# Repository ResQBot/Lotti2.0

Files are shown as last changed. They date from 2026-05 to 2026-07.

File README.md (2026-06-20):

# Lotti2.0 by Res.Q Bots Austria

Lotti2.0 is the seccond generation of our tracked **U**rban **S**earch and **E**xploration **R**obot (or USER).

We hope that any info you find in this repository helps you in your quest to develop your own USER, or robot of any other kind.
If you have any questions or want to partner up, feel free to contact us.

## Repository content:

### getting_started
contains a (more or less) detailed introduction to the whole topic of using Ubuntu and ROS, using our ROS packages and how to develop your own. This is a work in progress and you will definitely need addittional information to get deeper into ROS development.

### hardware
contains all (more or less) the hardware information and the CAD files.

### resources
contains user manuals, guidebooks, datasheets, etc. for motory, sensors, parts, ... used in our current robot.

### src 
contains our **ROS2 code** to control the robot and make use of its sensors.

&nbsp;
## Disclaimer
Please remember, that we are not professionals in the field of robotics, but merely curious students fooling around. While (most) code and designs you'll find here may work for us, they might not work for you and we do not take any responsibility for potential danger arising from the use of our ideas.

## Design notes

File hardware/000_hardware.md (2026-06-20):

# 🚀 Lotti 2.0 Hardware and CAD

This folder contains the mechanical CAD design, hardware documentation, and Bill of Materials (BOM) for **Lotti 2.0**, our RoboCup Rescue League robot developed for the **2026 RoboCup World Championship in Incheon, South Korea**.

The documentation explains the project structure, design philosophy, and the components used to build the robot.

---

# 📂 CAD Description

The main assembly, **`Lotti2_Main Assembly`**, contains the complete robot including the manipulator arm.

To simplify transportation and maintenance, the robot is divided into several modular assemblies.

## 🏗️ Center Module

Contains the main electronic components, including:

* Power distribution system
* Onboard computers
* Flipper mechanism motors

## ⚙️ Passive E-Module

Contains:

* Bearing-mounted shafts
* Structural drivetrain components
* Passive track support elements

No active drivetrain components are installed in this module.

## 🔩 Active E-Module

Contains:

* Chain drive motors
* Track drivetrain
* Transmission shafts
* Power transmission components

## 🤖 Manipulator Arm Assembly

Contains:

* Complete robotic arm
* End-effector mounting structure
* Arm electronics and sensors
* Mechanical transmission components

---

## 🎯 Design Philosophy

The modular design provides several advantages:

* Easier transportation
* Faster assembly during competitions
* Simplified maintenance
* Rapid replacement of damaged modules
* Improved accessibility to electronics and drivetrain components

---

# 📋 Bill of Materials (BOM)

## Main Robot

| Item No. | Component | Qty. | Notes | Manufacturer / Supplier |
| --- | --- | ---- | --- | --- |
| 1 | CubeMars AK10-9 V2.0 KV60 | 2 | Chain drive motors | https://www.cubemars.com/de/product/ak10-9-v2-0-kv60-robotic-actuator.html  |
| 2 | Unitree GO-M8010-6 Motor | 4 | Flipper mechanism | https://shop.unitree.com/products/go1-motor |
| 3 | Aluminum Profile 20x20 Type B Slot 6 | – | Center module frame | https://www.motedis.at/de/Aluprofil-20x20-B-Typ-Nut-6 |
| 4 | Internal Corner Bracket 21.6×21.6×15.8 | 16 | Structural frame | https://3d24.com/Winkel-Innenwinkel-21-6x21-6x15-8-Stahlguss-verzinkt/12560 |
| 5 | M4 T-Slot Nut Type B Slot 6 | 70 | Frame assembly | https://3d24.com/Nutenstein-M4-Nut-6-Typ-B-mit-Steg-Stahl-verzinkt/10697 |
| 6 | MINIX Z300-0dB | 1 | Main compute unit | https://www.minix.com.hk/products/minix-z300-0db-fanless-mini-pc-eu |
| 7 | Greenworks G24B4 Battery | 6 | Used with custom battery management system | https://greenworkstools.eu/products/24v-battery-4ah |
| 8 | Timing Belt | 4 | – | – |
| 9 | Waterjet-Cut Parts | – | Custom manufactured | – |
| 10 | Tower Profile | – | -- | – |
| 11 | Emergency Stop Switch | 1 | Safety system | https://www.conrad.at |
| 12 | Cameras | – | Vision system | – |
| 13 | Livox MID-360 | 1 | LiDAR sensor | https://www.livoxtech.com/de/mid-360 |
| 14 | HDMI Bulkhead Connector | 1 | External access port | Amazon |
| 15 | USB Extension | 1 | External access port | – |
| 16 | LAN Extension | 1 | External access port | – |
| 17 | PoolCare Track Belt | 4 | Flipper chain | https://www.hellopool.de/de/p/11620 |
| 18 | Waveshare USB-to-CAN Adapter | 1 | CAN communication | Amazon |
| 19 | XT60 Connector | 2 | Power interface | https://www.reichelt.at |
| 20 | M12 Sensor Cable (4-pin) | 1 | Sensor connection | https://www.reichelt.at |
| 21 | Amphenol M12A-04PFFP-SF8001 Socket | 1 | External interface | https://www.mouser.at |

---

## 🦾 Manipulator Arm

| Item No. | Component | Qty. | Notes | Manufacturer / Supplier |
| --- | --- | --- | --- | --- |
| 1 | Sweep Dynamics Cricket Drive MK II | 6 | Gearboxes | https://www.sweepdynamics.com/products/8247658741794 |
| 2 | NEMA 17 (23 mm) | 2 | Joint actuators | https://www.omc-stepperonline.com |
| 3 | NEMA 17 Stepper Motor | 4 | Joint actuators | – |
| 4 | MakerBase Servo42D | 6 | Closed-loop stepper driver | https://makerbase3d.com |
| 5 | RS485 Dongle | 1 | Communication interface | – |
| 6 | Aluminum Profile | 500 mm | Arm structure | – |
| 7 | Aluminum Profile | 500 mm | Arm structure | – |
| 8 | Camera | 1 | Visual feedback | – |
| 9 | Thermal Camera | 1 | Victim detection | – |
| 10 | Magnetic Sensor | 1 | Position sensing | – |
| 11 | ESP Controller | 1 | Arm control electronics | – |
| 12 | M12 Cable | 1 | Power and communication | – |
| 13 | M12 Socket | 1 | External connection | – |
| 14 | XT60 Connector | 1 | Power connection | – |
| 15 | USB Socket | 1 | Data connection | – |

---

# 🖨️ Manufacturing

Several additional custom parts are used throughout the robot.

### FDM Printed Components

Most non-load-critical components are manufactured using FDM printing with:

* Nobufil ABSx
* Nobufil PCTG
* PLA

### SLS Printed Components

The remaining actuator and precision mechanical components are manufactured using **Selective Laser Sintering (SLS)** for improved strength and dimensional accuracy.

---

# 🏆 RoboCup 2026

This robot was developed for participation in the **RoboCup Rescue League World Championship 2026** in **Incheon, South Korea**.

nm

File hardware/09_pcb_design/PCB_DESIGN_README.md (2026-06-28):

# PCB Desing section
This is the PCB Design section of the storage and Documentation area

# Power Delivery
The Power delivery is split into two section, one section gets the two battery inputs, merges them to a stable 24V for further use and also secures two individual 24V lines for driving the Motors. A lot of measurements also happen here.

The other part is the Conversion to regulate the 24V for the Motors to 12V for some sensores, the STM32 and also the Control PC and optional 5V for other things.

## Open Problems witht the PCB (ideas and stuff for v3)
- Rework PD Traces
- include relay for smooth change for the PC 12V line.

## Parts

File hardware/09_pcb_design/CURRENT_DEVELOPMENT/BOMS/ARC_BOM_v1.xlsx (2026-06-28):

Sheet: ARC_SecBoard_v1
Reference | Qty | Value | MOUSER NR. | Gegenstück | DNP | Exclude from BOM | Exclude from Board | Footprint | Link | Datasheet
BAT1_INPUT1,BAT2_INPUT1,J6,J7,J8,J9,J10,J11 | 8 | VP026584000AG | 523-VP026584000AG |  |  |  |  | Bickel_STD_LIB:SHDR4W100P1016_2X2_2032X1830X2850P | https://www.mouser.at/ProductDetail/Amphenol-Anytek/VP026584000AG?qs=T3oQrply3y8ZXElTBVt2Rg%3D%3D | http://www.anytek.com.tw/UserUpFiles/20181025/d41_CP3hmn_a.pdf
C1,C2,C3,C4,C11,C12 | 6 | 1uF | 80-C0805X105J5RAUTO |  |  |  |  | Capacitor_SMD:C_0805_2012Metric_Pad1.18x1.45mm_HandSolder | https://www.mouser.at/ProductDetail/KEMET/C0805X105J5RACAUTO?qs=3Rah4i%252BhyCEIBfdnjuP76g%3D%3D | ~
C5,C8 | 2 | 4.7nF | 80-C0805C472F2GECAUT |  |  |  |  | Capacitor_SMD:C_0805_2012Metric_Pad1.18x1.45mm_HandSolder | https://www.mouser.at/ProductDetail/KEMET/C0805C472F2GECAUTO?qs=MLItCLRbWsxYq%252BaGNtguHw%3D%3D | ~
C6,C7,C9,C10,C14,C42 | 6 | 47nF | C0805C473F8TACTU (https://www.mouser.at/ProductDetail/KEMET/C0805C473F8TACTU?qs=Znm5pLBrcAKsHNAcWSl52g%3D%3D) |  |  |  |  | Capacitor_SMD:C_0805_2012Metric_Pad1.18x1.45mm_HandSolder | https://www.mouser.at/ProductDetail/KEMET/C0805C473F8TACTU?qs=Znm5pLBrcAKsHNAcWSl52g%3D%3D | ~
C15,C17,C18,C20 | 4 | 100nF | 80-C0805R104J5RACTU |  |  |  |  | Capacitor_SMD:C_0805_2012Metric_Pad1.18x1.45mm_HandSolder | https://www.mouser.at/ProductDetail/KEMET/C0805R104J5RACTU?qs=RcG8xmE7yp2JeihV4l474Q%3D%3D | ~
C16,C19 | 2 | 0.1uF | 80-C0805R104J5RACTU |  |  |  |  | Capacitor_SMD:C_0805_2012Metric_Pad1.18x1.45mm_HandSolder | https://www.mouser.at/ProductDetail/KEMET/C0805R104J5RACTU?qs=RcG8xmE7yp2JeihV4l474Q%3D%3D | ~
CurMeas_BATT1,CurMeas_BATT2 | 2 | HLSR_16-P | 61-HLSR16-P |  |  |  |  | Bickel_STD_LIB:HLSR16P | https://www.mouser.at/ProductDetail/LEM/HLSR-16-P?qs=Vi0JKjFBtYk%252B%2FFkGD82vGg%3D%3D
D1,D3 | 2 | 1N4007 | 637-1N4007 |  |  |  |  | Diode_THT:D_DO-41_SOD81_P10.16mm_Horizontal | https://www.mouser.at/ProductDetail/Diotec-Semiconductor/1N4007?qs=OlC7AqGiEDmK9mU1uTiCkg%3D%3D | http://www.vishay.com/docs/88503/1n4001.pdf
D2,D6 | 2 | BZX84Cxx | 637-BZX84C2V4 |  |  |  |  | Package_TO_SOT_SMD:SOT-23 | https://www.mouser.at/ProductDetail/Diotec-Semiconductor/BZX84C2V4?qs=OlC7AqGiEDkxkJbs7iMTqw%3D%3D | https://diotec.com/tl_files/diotec/files/pdf/datasheets/bzx84c2v4.pdf
D4,D5 | 2 | SMBJ26A-E3_52 | 625-SMBJ26A-E3 |  |  |  |  | Bickel_STD_LIB:DIOM5436X244N | https://www.mouser.at/ProductDetail/Vishay-General-Semiconductor/SMBJ26A-E3-52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 | http://www.vishay.com/docs/88392/smbj.pdf
FUSEHOLDER1,FUSEHOLDER2 | 2 | 30A | 576-178.6764.0001 |  |  |  |  | Bickel_STD_LIB:17867640001 | https://www.mouser.at/ProductDetail/Littelfuse/178.6764.0001?qs=gu7KAQ731UTQ5alyjBY5mw%3D%3D | http://www.littelfuse.com/~/media/commercial-vehicle/datasheets/automotive-fuse-holders/mini/littelfuse-fuseholder-mini-fl1-pcb-mount.pdf
IC1,IC4 | 2 | FDS6690A | 512-FDS6690A |  |  |  |  | Bickel_STD_LIB:SOIC127P600X175-8N | https://www.mouser.at/ProductDetail/onsemi/FDS6690A?qs=HK%252BeIG1iaajCQ7GvPyNvug%3D%3D | https://www.onsemi.com/pub/Collateral/FDS6690A-D.PDF
IC7 | 1 | PI4ULS5V202UEX | 729-PI4ULS5V202UEX |  |  |  |  | Bickel_STD_LIB:SOP65P490X110-8N | https://www.mouser.at/ProductDetail/Diodes-Incorporated/PI4ULS5V202UEX?qs=iC14BvcgY%2F0LieFnOYBbzw%3D%3D | https://www.diodes.com//assets/Datasheets/PI4ULS5V202.pdf
J1 | 1 | EmerStop_Con1 | 737-25SH-B-02-TR | 737-25CH-B-02 + 737-25CTB-R |  |  |  | Bickel_STD_LIB:25SHB02TR | https://www.mouser.at/ProductDetail/Adam-Tech/25SH-B-02-TR?qs=HoCaDK9Nz5ewYeC9%2FRQ9dg%3D%3D | https://app.adam-tech.com/products/download/data_sheet/196905/25sh-b-xx-tr-data-sheet.pdf
J2 | 1 | EmerStop_Con2 | 737-25SH-B-02-TR | 737-25CH-B-02 + 737-25CTB-R |  |  |  | Bickel_STD_LIB:25SHB02TR | https://www.mouser.at/ProductDetail/Adam-Tech/25SH-B-02-TR?qs=HoCaDK9Nz5ewYeC9%2FRQ9dg%3D%3D | https://app.adam-tech.com/products/download/data_sheet/196905/25sh-b-xx-tr-data-sheet.pdf
J3 | 1 | 640455-5 | 571-6404555 | 571-1375820-5 + 571-13758193 |  |  |  | Bickel_STD_LIB:HDRRA5W88P0X254_1X5_1270X775X610P | https://www.mouser.at/ProductDetail/TE-Connectivity/640455-5?qs=X1mjqRbeMc5kyjdl11VSpA%3D%3D | https://www.te.com/commerce/DocumentDelivery/DDEController?Action=srchrtrv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
J4,J5 | 2 | 1792863 | 651-1792863 |  |  |  |  | Bickel_STD_LIB:1792863 | https://www.mouser.at/ProductDetail/Phoenix-Contact/1792863?qs=YjJcVSlHJPU69DDcZ8WVCg%3D%3D | https://www.phoenixcontact.com/online/portal/pi/pxc/product_detail_page/!ut/p/z1/5VddT_IwFP4rvBfcWdp9j0ucREDRGUDZbpa260h1X24V1F9vCzNEo_PCePFmy0nWduec9nl6DuGBI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
J12 | 1 | 25SH-B-02-TR | 737-25SH-B-02-TR | 737-25CH-B-02 + 737-25CTB-R |  |  |  | Bickel_STD_LIB:25SHB02TR | https://www.mouser.at/ProductDetail/JST-Commercial/B4B-XH-ALFSN?qs=cdbOS8ANM9CfC08d%252BywhFw%3D%3D | https://app.adam-tech.com/products/download/data_sheet/196905/25sh-b-xx-tr-data-sheet.pdf
J22 | 1 | B4B-XH-A_LF__SN_ | 306-B4BXHALFSN |  |  |  |  | Bickel_STD_LIB:B4BXHALFSN | https://www.mouser.at/ProductDetail/JST-Commercial/B4B-XH-ALFSN?qs=cdbOS8ANM9CfC08d%252BywhFw%3D%3D | https://datasheet.lcsc.com/szlcsc/JST-Sales-America-B4B-XH-A-LF-SN_C144395.pdf
J28,J37 | 2 | 25SHB02TR | 306-B4BXHALFSN |  |  |  |  | Bickel_STD_LIB:25SHB02TR | https://www.mouser.at/ProductDetail/JST-Commercial/B4B-XH-ALFSN?qs=cdbOS8ANM9CfC08d%252BywhFw%3D%3D | https://app.adam-tech.com/products/download/data_sheet/196905/25sh-b-xx-tr-data-sheet.pdf
K1,K2 | 2 | T9AS1D12-24 | 655-T9AS1D12-24 |  |  |  |  | Bickel_STD_LIB:T9AS1D1224 | 655-T9AS1D12-24 | https://www.te.com/commerce/DocumentDelivery/DDEController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
Q1,Q6 | 2 | BSS138 | 512-BSS138 |  |  |  |  | Package_TO_SOT_SMD:SOT-23 | https://www.mouser.at/ProductDetail/onsemi/BSS138?qs=HK%252BeIG1iaahCeqBvjB4arg%3D%3D | https://www.onsemi.com/pub/Collateral/BSS138-D.PDF
Q2,Q3 | 2 | IPD70P04P4L08ATMA2 | 726-IPD70P04P4L08ATM |  |  |  |  | Bickel_STD_LIB:IPD70P04P4L08ATMA2 | https://www.mouser.at/ProductDetail/Infineon-Technologies/IPD70P04P4L08ATMA2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 | https://www.infineon.com/dgdl/Infineon-IPD70P04P4L-08-DataSheet-v01_02-EN.pdf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
R1,R3,R5,R7 | 4 | 6k8 | 756-WCR1206-6K8FI |  |  |  |  | Resistor_SMD:R_1206_3216Metric_Pad1.30x1.75mm_HandSolder | https://www.mouser.at/ProductDetail/Welwyn-Components-TT-Electronics/WCR1206-6K8FI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 | ~
R2,R4,R6,R8 | 4 | 1k | 756-WCR1206-1K0FI |  |  |  |  | Resistor_SMD:R_1206_3216Metric_Pad1.30x1.75mm_HandSolder | https://www.mouser.at/ProductDetail/Welwyn-Components-TT-Electronics/WCR1206-1K0FI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 | ~
R9,R11,R14,R18 | 4 | 5k1 | 756-WCR1206-5K1FI |  |  |  |  | Resistor_SMD:R_1206_3216Metric_Pad1.30x1.75mm_HandSolder | https://www.mouser.at/ProductDetail/Welwyn-Components-TT-Electronics/WCR1206-5K1FI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 | ~
R10,R12,R31,R33,R32 | 4 | 10k | 756-WCR1206-10KFI |  |  |  |  | Resistor_SMD:R_1206_3216Metric_Pad1.30x1.75mm_HandSolder | https://www.mouser.at/ProductDetail/Welwyn-Components-TT-Electronics/WCR1206-10KFI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 | ~
R13,R17 | 2 | 100kOhm | 756-WCR1206-100KFI |  |  |  |  | Resistor_SMD:R_1206_3216Metric_Pad1.30x1.75mm_HandSolder | https://www.mouser.at/ProductDetail/Welwyn-Components-TT-Electronics/WCR1206-100KFI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 | ~
U2,U7 | 2 | LM74700 | 595-LM74700QDBVRQ1 |  |  |  |  | Package_TO_SOT_SMD:SOT-23-6 | https://www.mouser.at/ProductDetail/Texas-Instruments/LM74700QDBVRQ1?qs=j%252B1pi9TdxUYjAZhGV8eSkQ%3D%3D | http://www.ti.com/lit/gpn/LM74700-Q1
U4 | 1 | NUCLEO-L432KC | 511-NUCLEO-L432KC | 872-920-0171-01 |  |  |  | NUCLEO:MODULE_NUCLEO-L432KC | https://www.mouser.at/ProductDetail/STMicroelectronics/NUCLEO-L432KC?qs=qzCNEk%252BRr%252BajjPvxjwWK5g%3D%3D

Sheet: ARC_ConBoard_v1
Reference | Qty | Value | MOUSER NR. | Gegenstück | Link | DNP | Exclude from BOM | Exclude from Board | Footprint | Link2 | Datasheet
C21,C28 | 2 | C5750X7S2A156M250KB | 810-C5750X7S2A156M |  | https://www.mouser.at/ProductDetail/TDK/C5750X7S2A156M250KB?qs=NRhsANhppD%2F9BqQqutmwLg%3D%3D |  |  |  | Bickel_STD_LIB:C5750_Commercial |  | https://product.tdk.com/system/files/dam/doc/product/capacitor/ceramic/mlcc/catalog/mlcc_commercial_midvoltage_en.pdf
C22,C29,C38,C40,C39 | 5 | 100nF | 80-C0805R104J5RACTU |  | https://www.mouser.at/ProductDetail/KEMET/C0805R104J5RACTU?qs=RcG8xmE7yp2JeihV4l474Q%3D%3D |  |  |  | Capacitor_SMD:C_0805_2012Metric_Pad1.18x1.45mm_HandSolder |  | ~
C23,C30 | 2 | 15nF | 80-C0805C153K5HAUTO |  | https://www.mouser.at/ProductDetail/KEMET/C0805C153K5HACAUTO?qs=2FIyTMJ0hNmdPhqlC7uDGg%3D%3D |  |  |  | Capacitor_SMD:C_0805_2012Metric_Pad1.18x1.45mm_HandSolder |  | ~
C24,C31 | 2 | 2.2uF | 80-C0805X225K3RAUTO |  | https://www.mouser.at/ProductDetail/KEMET/C0805X225K3RACAUTO?qs=HBWAp0VN4RiOFLf7ztePRQ%3D%3D |  |  |  | Capacitor_SMD:C_0805_2012Metric_Pad1.18x1.45mm_HandSolder |  | ~
C25,C32 | 2 | 470nF | 80-C1206C474M1REAULR |  | https://www.mouser.at/ProductDetail/KEMET/C1206C474M1RECAUTO7210?qs=55YtniHzbhDbiphzg7KKzQ%3D%3D |  |  |  | Capacitor_SMD:C_1206_3216Metric_Pad1.33x1.80mm_HandSolder |  | ~
C26,C33,C34,C262 | 4 | 100pF | 80-C0805C101F1G |  | https://www.mouser.at/ProductDetail/KEMET/C0805C101F1GACTU?qs=PvkUd2vn8WpeBlgrApNklg%3D%3D |  |  |  | Capacitor_SMD:C_0805_2012Metric_Pad1.18x1.45mm_HandSolder |  | ~
C27,C35 | 2 | EEH-ZC1E560P | 667-EEH-ZC1E560P |  | https://www.mouser.at/ProductDetail/Panasonic/EEH-ZC1E560P?qs=7UCyOFMWVHYdN59awcl%252BRg%3D%3D |  |  |  | Bickel_STD_LIB:EEHZA1E101XP |  | http://industrial.panasonic.com/cdbs/www-data/pdf/RDD0000/ABA0000C1234.pdf
C36 | 1 | 10uF | 80-C0805X106J8RAUTO |  | https://www.mouser.at/ProductDetail/KEMET/C0805X106J8RACAUTO?qs=HXFqYaX1Q2wKi4kcOiFe3g%3D%3D |  |  |  | Capacitor_SMD:C_0805_2012Metric_Pad1.18x1.45mm_HandSolder |  | ~
C37 | 1 | 22uF | 80-C0805C226K9PACTU |  | https://www.mouser.at/ProductDetail/KEMET/C0805C226K9PACTU?qs=CmJlwSR1kv6i2XEByn7wWw%3D%3D |  |  |  | Capacitor_SMD:C_0805_2012Metric_Pad1.18x1.45mm_HandSolder |  | ~
D7 | 1 | 1N4007 | 637-1N4007 |  | https://www.mouser.at/ProductDetail/Diotec-Semiconductor/1N4007?qs=OlC7AqGiEDmK9mU1uTiCkg%3D%3D |  |  |  | Diode_THT:D_DO-41_SOD81_P10.16mm_Horizontal |  | http://www.vishay.com/docs/88503/1n4001.pdf
IC2 | 1 | FDS6690A | 512-FDS6690A |  | https://www.mouser.at/ProductDetail/onsemi/FDS6690A?qs=HK%252BeIG1iaajCQ7GvPyNvug%3D%3D |  |  |  | Bickel_STD_LIB:SOIC127P600X175-8N |  | https://www.onsemi.com/pub/Collateral/FDS6690A-D.PDF
J3 | 1 | 640455-5 | 571-6404555 | 571-1375820-5 + 571-13758193 | https://www.mouser.at/ProductDetail/TE-Connectivity/640455-5?qs=X1mjqRbeMc5kyjdl11VSpA%3D%3D |  |  |  | Bickel_STD_LIB:HDRRA5W88P0X254_1X5_1270X775X610P |  | https://www.te.com/commerce/DocumentDelivery/DDEController?Action=srchrtrv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
J4 | 1 | 1792863 | 651-1792863 |  | https://www.mouser.at/ProductDetail/Phoenix-Contact/1792863?qs=YjJcVSlHJPU69DDcZ8WVCg%3D%3D |  |  |  | Bickel_STD_LIB:1792863 |  | https://www.phoenixcontact.com/online/portal/pi/pxc/product_detail_page/!ut/p/z1/5VddT_IwFP4rvBfcWdp9j0ucREDRGUDZbpa260h1X24V1F9vCzNEo_PCePFmy0nWduec9nl6DuGBI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
J8,J10 | 2 | USB_C_Receptacle_PowerOnly_6P | 179-UJCHGSMT2P6TR |  | https://www.mouser.at/ProductDetail/Same-Sky/UJC-H-G-SMT-2-P6-TR?qs=IKkN%2F947nfApFV8T6rOqww%3D%3D |  |  |  | Bickel_STD_LIB:UJCHGSMT2P6TR |  | https://www.usb.org/sites/default/files/documents/usb_type-c.zip
J15,J16,J26,J27,J21,J23 | 6 | 1792863 | 651-1792863 |  | https://www.mouser.at/ProductDetail/Phoenix-Contact/1755736?qs=wd%252Bw3mUqFrlo9zPE3AUt1w%3D%3D |  |  |  | Bickel_STD_LIB:1792863 |  | https://www.phoenixcontact.com/online/portal/pi/pxc/product_detail_page/!ut/p/z1/5VddT_IwFP4rvBfcWdp9j0ucREDRGUDZbpa260h1X24V1F9vCzNEo_PCePFmy0nWduec9nl6DuGBI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
L1,L2 | 2 | 7443641000B | 710-7443641000B |  | https://www.mouser.at/ProductDetail/Wurth-Elektronik/7443641000B?qs=u16ybLDytRZnRSotE5ElWA%3D%3D |  |  |  | Bickel_STD_LIB:7443641000B |  | https://www.we-online.com/catalog/datasheet/7443641000B.pdf
Q4,Q7 | 2 | CSD18504Q5A | 595-CSD18504Q5A |  | https://www.mouser.at/ProductDetail/Texas-Instruments/CSD18504Q5A?qs=yHb6XuIhq3dvLuAUdb%252BIdg%3D%3D |  |  |  | Package_TO_SOT_SMD:TDSON-8-1 |  | http://www.ti.com/lit/gpn/csd18504q5a
Q5,Q8 | 2 | CSD18533Q5A | 595-CSD18533Q5A |  | https://www.mouser.at/ProductDetail/Texas-Instruments/CSD18533Q5A?qs=vnbNJPHmPnOmoe5pzm7%252BFQ%3D%3D |  |  |  | Package_TO_SOT_SMD:TDSON-8-1 |  | http://www.ti.com/lit/gpn/csd18533q5a
R19,R23 | 2 | 348k | 652-CR1206FX-3483ELF |  | https://www.mouser.at/ProductDetail/Bourns/CR1206-FX-3483ELF?qs=raSpJxvwqHGuX%2FO%252BDdTCKQ%3D%3D |  |  |  | Resistor_SMD:R_1206_3216Metric_Pad1.30x1.75mm_HandSolder |  | ~
R20,R24 | 2 | 604R | 652-CR1206FX-6040ELF |  | https://www.mouser.at/ProductDetail/Bourns/CR1206-FX-6040ELF?qs=x5wsLs3ZZ82RbeZRknvCkg%3D%3D |  |  |  | Resistor_SMD:R_1206_3216Metric_Pad1.30x1.75mm_HandSolder |  | ~
R21,R25 | 2 | 191k | 652-CR1206FX-1913ELF |  | https://www.mouser.at/ProductDetail/Bourns/CR1206-FX-1913ELF?qs=QdEzPYIOmZiiRy0dJvxDtg%3D%3D |  |  |  | Resistor_SMD:R_1206_3216Metric_Pad1.30x1.75mm_HandSolder |  | ~
R22,R26,R27,R28,R29,R30 | 2 | 10k | 756-WCR1206-10KFI |  | https://www.mouser.at/ProductDetail/Welwyn-Components-TT-Electronics/WCR1206-10KFI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 |  |  |  | Resistor_SMD:R_1206_3216Metric_Pad1.30x1.75mm_HandSolder |  | ~
U3,U8 | 2 | LM3150MH | 926-LM3150MH/NOPB |  | https://www.mouser.at/ProductDetail/Texas-Instruments/LM3150MH-NOPB?qs=X1J7HmVL2ZHJ%2FS5n%2FpwmDw%3D%3D |  |  |  | Package_SO:Texas_HTSSOP-14-1EP_4.4x5mm_P0.65mm_EP3.4x5mm_Mask3.155x3.255mm_ThermalVias |  | http://www.ti.com/lit/ds/symlink/lm3150.pdf
U9 | 1 | RPM5.0-6.0 | 919-RPM5.0-6.0 |  | https://www.mouser.at/ProductDetail/RECOM-Power/RPM5.0-6.0?qs=qSfuJ%252Bfl%2Fd6RhQVkKT5WeQ%3D%3D |  |  |  | Converter_DCDC:Converter_DCDC_RECOM_RPMx.x-x.0 |  | https://www.recom-power.com/pdf/Innoline/RPM-6.0.pdf
U10 | 1 | LM74700 | 595-LM74700QDBVRQ1 |  | https://www.mouser.at/ProductDetail/Texas-Instruments/LM74700QDBVRQ1?qs=j%252B1pi9TdxUYjAZhGV8eSkQ%3D%3D |  |  |  | Package_TO_SOT_SMD:SOT-23-6 |  | http://www.ti.com/lit/gpn/LM74700-Q1
U12 | 1 | ALQ1F24RS | 769-ALQ1F24RS |  | https://www.mouser.at/ProductDetail/Panasonic-Industrial-Devices/ALQ1F24RS?qs=HMhDvBYWqvN6BZkblV4aOA%3D%3D |  |  |  | Bickel_STD_LIB:ALQ112S |  | https://industry.panasonic.com/ac/cdn/e/control/relay/power/catalog/mech_eng_lq.pdf

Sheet: ARC_ConBoard_v2
Id | Designator | Footprint | Quantity | Designation | Supplier and ref | Column1 | _1
1 | C8,C9,C36,C7 | C_0805_2012Metric_Pad1.18x1.45mm_HandSolder | 4 | 10uF
2 | D7 | D_DO-41_SOD81_P10.16mm_Horizontal | 1 | 1N4007
3 | J23,J26,J16,J4,J21,J27,J15 | 1792863 | 7 | 1792863
4 | J10,J8 | UJCHGSMT2P6TR | 2 | USB_C_Receptacle_PowerOnly_6P
5 | L2 | 7443641000B | 1 | 7443641000B
6 | C11,C6,C39,C29,C38,C40 | C_0805_2012Metric_Pad1.18x1.45mm_HandSolder | 6 | 100nF
7 | U12 | ALQ112S | 1 | ALQ1F24RS
8 | R4 | R_0805_2012Metric_Pad1.20x1.40mm_HandSolder | 1 | 40.2k
9 | C13 | C_0805_2012Metric_Pad1.18x1.45mm_HandSolder | 1 | 24p
10 | J3 | HDRRA5W88P0X254_1X5_1270X775X610P | 1 | 640455-5
11 | R1 | R_Axial_DIN0414_L11.9mm_D4.5mm_P15.24mm_Horizontal | 1 | 5mR
12 | IC3 | IAUC120N06S5N011ATMA1 | 1 | IAUCN04S7L028ATMA1
13 | R5 | R_0805_2012Metric_Pad1.20x1.40mm_HandSolder | 1 | 9.53k
14 | R24 | R_1206_3216Metric_Pad1.30x1.75mm_HandSolder | 1 | 604R
15 | R25 | R_1206_3216Metric_Pad1.30x1.75mm_HandSolder | 1 | 191k
16 | C12 | C_0805_2012Metric_Pad1.18x1.45mm_HandSolder | 1 | 680pF
17 | R27,R26,R28,R29,R30 | R_1206_3216Metric_Pad1.30x1.75mm_HandSolder | 5 | 10k
18 | C35,C1,C2 | EEHZA1E101XP | 3 | EEH-ZC1E560P
19 | U10 | SOT-23-6 | 1 | LM74700
20 | R6 | R_0805_2012Metric_Pad1.20x1.40mm_HandSolder | 1 | 6.04k
21 | C37 | C_0805_2012Metric_Pad1.18x1.45mm_HandSolder | 1 | 22uF
22 | C30 | C_0805_2012Metric_Pad1.18x1.45mm_HandSolder | 1 | 15nF
23 | C34,C33 | C_0805_2012Metric_Pad1.18x1.45mm_HandSolder | 2 | 100pF
24 | Q1 | CSD18514Q5A | 1 | CSD18514Q5A
25 | R3 | R_0805_2012Metric_Pad1.20x1.40mm_HandSolder | 1 | 47.5k
26 | C3,C5,C4 | C_0805_2012Metric_Pad1.18x1.45mm_HandSolder | 3 | 4.7uF
27 | Q8 | TDSON-8-1 | 1 | CSD18533Q5A
28 | U3 | Texas_HTSSOP-14-1EP_4.4x5mm_P0.65mm_EP3.4x5mm_Mask3.155x3.255mm_ThermalVias | 1 | LM3150MH
29 | C31,C10 | C_0805_2012Metric_Pad1.18x1.45mm_HandSolder | 2 | 2.2uF
30 | Q7 | TDSON-8-1 | 1 | CSD18504Q5A
31 | L1 | XAL6030102MEC | 1 | XAL6030-102MEC
32 | R2 | R_0805_2012Metric_Pad1.20x1.40mm_HandSolder | 1 | 100k
33 | IC2 | SOIC127P600X175-8N | 1 | FDS6690A
34 | R23 | R_1206_3216Metric_Pad1.30x1.75mm_HandSolder | 1 | 348k
35 | U9 | Converter_DCDC_RECOM_RPMx.x-x.0 | 1 | RPM5.0-6.0
36 | C32 | C_1206_3216Metric_Pad1.33x1.80mm_HandSolder | 1 | 470nF
37 | C28 | C5750_Commercial | 1 | C5750X7S2A156M250KB
38 | IC1 | LM5148RGYR | 1 | LM5148RGYR

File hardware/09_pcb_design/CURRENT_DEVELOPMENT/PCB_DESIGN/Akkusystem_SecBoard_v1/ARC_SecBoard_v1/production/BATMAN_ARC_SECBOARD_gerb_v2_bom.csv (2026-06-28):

Designator | Footprint | Quantity | Value | LCSC Part #
BAT1_INPUT1, BAT2_INPUT1, J10, J11, J6, J7, J8, J9 | SHDR4W100P1016_2X2_2032X1830X2850P | 8 | VP026584000AG
C1, C11, C12, C2, C3, C4 | 0805 | 6 | 1uF
C10, C14, C42, C6, C7, C9 | 0805 | 6 | 47nF
C13, C21, C22, C23, C24, C25 | CAPPRD150W45D400H850 | 6 | ESY106M035AB2AA
C15, C17, C18, C20 | 0805 | 4 | 100nF
C16, C19 | 0805 | 2 | 0.1uF
C5, C8 | 0805 | 2 | 4.7nF
CURMEAS_BATT1, CURMEAS_BATT2 | HLSR16P | 2 | HLSR_16-P
D1, D3 | D_DO-41_SOD81_P10.16mm_Horizontal | 2 | 1N4007
D2, D6 | SOT-23 | 2 | BZX84Cxx
D4, D5 | DIOM5436X244N | 2 | SMBJ26A-E3_52
FUSEHOLDER1, FUSEHOLDER2 | 17867640001 | 2 | 30A
IC1, IC4 | SOIC127P600X175-8N | 2 | FDS6690A
IC7 | SOP65P490X110-8N | 1 | PI4ULS5V202UEX
J1 | 25SHB02TR | 1 | EmerStop_Con1
J12 | 25SHB02TR | 1 | 25SH-B-02-TR
J2 | 25SHB02TR | 1 | EmerStop_Con2
J22 | B4BXHALFSN | 1 | B4B-XH-A_LF__SN_
J28 | 25SHB02TR | 1 | 25SHB02TR
J3 | HDRRA5W88P0X254_1X5_1270X775X610P | 1 | 640455-5
J37 | 25SHB02TR | 1 | B2B-XH-A__LF__SN_
J4, J5 | 1792863 | 2 | 1792863
K1, K2 | T9AS1D1224 | 2 | T9AS1D12-24
Q1, Q6 | SOT-23 | 2 | BSS138
Q2, Q3 | IPD70P04P4L08ATMA2 | 2 | IPD70P04P4L08ATMA2
R1, R3, R5, R7 | 1206 | 4 | 6k8
R10, R12, R31, R32, R33 | 1206 | 5 | 10k
R11, R14, R18, R9 | 1206 | 4 | 5k1
R13, R17 | 1206 | 2 | 100kOhm
R2, R4, R6, R8 | 1206 | 4 | 1k
U2, U7 | SOT-23-6 | 2 | LM74700
U4 | MODULE_NUCLEO-L432KC | 1 | NUCLEO-L432KC

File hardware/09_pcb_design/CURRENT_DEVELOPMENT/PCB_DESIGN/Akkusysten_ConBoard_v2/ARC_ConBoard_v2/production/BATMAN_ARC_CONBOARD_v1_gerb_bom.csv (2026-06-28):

Designator | Footprint | Quantity | Value | LCSC Part #
C1, C2, C27, C35 | EEHZA1E101XP | 4 | EEH-ZC1E560P
C21, C28 | C5750_Commercial | 2 | C5750X7S2A156M250KB
C22, C29, C38, C39, C40 | 0805 | 5 | 100nF
C23, C30 | 0805 | 2 | 15nF
C24, C31 | 0805 | 2 | 2.2uF
C25, C32 | 1206 | 2 | 470nF
C26, C262, C33, C34 | 0805 | 4 | 100pF
C36 | 0805 | 1 | 10uF
C37 | 0805 | 1 | 22uF
D7 | D_DO-41_SOD81_P10.16mm_Horizontal | 1 | 1N4007
IC2 | SOIC127P600X175-8N | 1 | FDS6690A
J10, J8 | UJCHGSMT2P6TR | 2 | USB_C_Receptacle_PowerOnly_6P
J15, J16, J21, J23, J26, J27, J4 | 1792863 | 7 | 1792863
J3 | HDRRA5W88P0X254_1X5_1270X775X610P | 1 | 640455-5
L1, L2 | 7443641000B | 2 | 7443641000B
Q4, Q7 | TDSON-8-1 | 2 | CSD18504Q5A
Q5, Q8 | TDSON-8-1 | 2 | CSD18533Q5A
R19, R23 | 1206 | 2 | 348k
R20, R24 | 1206 | 2 | 604R
R21, R25 | 1206 | 2 | 191k
R22, R26, R27, R28, R29, R30 | 1206 | 6 | 10k
U10 | SOT-23-6 | 1 | LM74700
U12 | ALQ112S | 1 | ALQ1F24RS
U3, U8 | Texas_HTSSOP-14-1EP_4.4x5mm_P0.65mm_EP3.4x5mm_Mask3.155x3.255mm_ThermalVias | 2 | LM3150MH
U9 | Converter_DCDC_RECOM_RPMx.x-x.0 | 1 | RPM5.0-6.0

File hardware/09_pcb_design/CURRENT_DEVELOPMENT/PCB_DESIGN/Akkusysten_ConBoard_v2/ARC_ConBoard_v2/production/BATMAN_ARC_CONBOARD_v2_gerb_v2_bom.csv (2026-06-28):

Designator | Footprint | Quantity | Value | LCSC Part #
C1, C2, C35 | EEHZA1E101XP | 3 | EEH-ZC1E560P
C10, C31 | 0805 | 2 | 2.2uF
C11, C29, C38, C39, C40, C6 | 0805 | 6 | 100nF
C12 | 0805 | 1 | 680pF
C13 | 0805 | 1 | 24p
C28 | C5750_Commercial | 1 | C5750X7S2A156M250KB
C3, C4, C5 | 0805 | 3 | 4.7uF
C30 | 0805 | 1 | 15nF
C32 | 1206 | 1 | 470nF
C33, C34 | 0805 | 2 | 100pF
C36, C7, C8, C9 | 0805 | 4 | 10uF
C37 | 0805 | 1 | 22uF
D7 | D_DO-41_SOD81_P10.16mm_Horizontal | 1 | 1N4007
IC1 | LM5148RGYR | 1 | LM5148RGYR
IC2 | SOIC127P600X175-8N | 1 | FDS6690A
IC3 | IAUC120N06S5N011ATMA1 | 1 | IAUCN04S7L028ATMA1
J10, J8 | UJCHGSMT2P6TR | 2 | USB_C_Receptacle_PowerOnly_6P
J15, J16, J21, J23, J26, J27, J4 | 1792863 | 7 | 1792863
J3 | HDRRA5W88P0X254_1X5_1270X775X610P | 1 | 640455-5
L1 | XAL6030102MEC | 1 | XAL6030-102MEC
L2 | 7443641000B | 1 | 7443641000B
Q1 | CSD18514Q5A | 1 | CSD18514Q5A
Q7 | TDSON-8-1 | 1 | CSD18504Q5A
Q8 | TDSON-8-1 | 1 | CSD18533Q5A
R1 | R_Axial_DIN0414_L11.9mm_D4.5mm_P15.24mm_Horizontal | 1 | 5mR
R2 | 0805 | 1 | 100k
R23 | 1206 | 1 | 348k
R24 | 1206 | 1 | 604R
R25 | 1206 | 1 | 191k
R26, R27, R28, R29, R30 | 1206 | 5 | 10k
R3 | 0805 | 1 | 47.5k
R4 | 0805 | 1 | 40.2k
R5 | 0805 | 1 | 9.53k
R6 | 0805 | 1 | 6.04k
U10 | SOT-23-6 | 1 | LM74700
U12 | ALQ112S | 1 | ALQ1F24RS
U3 | Texas_HTSSOP-14-1EP_4.4x5mm_P0.65mm_EP3.4x5mm_Mask3.155x3.255mm_ThermalVias | 1 | LM3150MH
U9 | Converter_DCDC_RECOM_RPMx.x-x.0 | 1 | RPM5.0-6.0

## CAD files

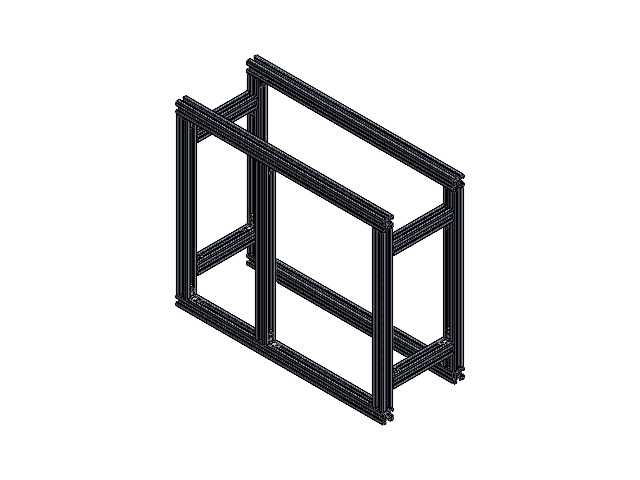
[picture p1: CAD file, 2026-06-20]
hardware/00_CAD/BG_Body/01_Mittelteil/00_BG_Rahmen_mittelteil.SLDASM
MT_Hoehe (110mm) x 4
MT_Längsstrebe (380mm) x 4
MT_Querstrebe (286mm) x 5
MT_Winkel_90_Grad x 18

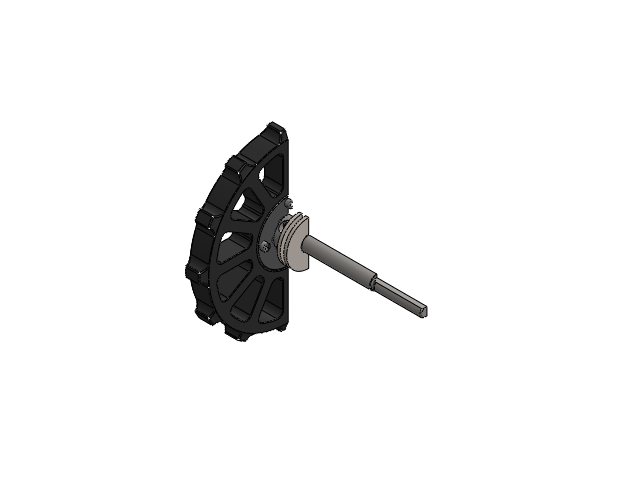
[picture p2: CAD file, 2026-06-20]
hardware/00_CAD/BG_Body/02_Vorne_hinten/03_Wellen_und_Antrieb/01_Aktiver_Teil/00_BG_Welle_vierkant.SLDASM
WA_Welle_vierkant
WA_Antriebsrad_V2
WA_Antriebsrad_Buchse_Motor
WA_Antriebsrad_Buchse_Motor_vierkant
WA_M4x25_BA2 x 4
WA_HNTL1N-ST-M4 x 4
WA_Klemmring __12mm
WA_Zwischenhülse Nadellager
WA_Nadellager-BLACKBOX
plain washer large_din x 2
WA_Abstandsplatte_Motor

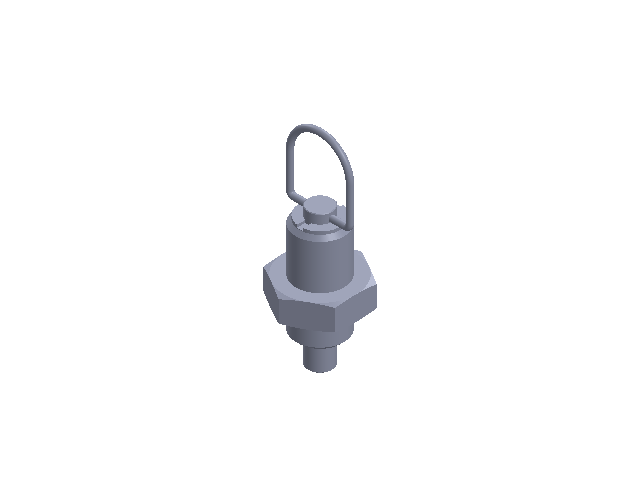
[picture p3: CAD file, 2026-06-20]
hardware/00_CAD/BG_Body/03_Flipper/04_Riemenspanner/175761787-7-gn_26411/FP_gn_26411.SLDASM
20251231gn_26411_01
20251231gn_26411_02

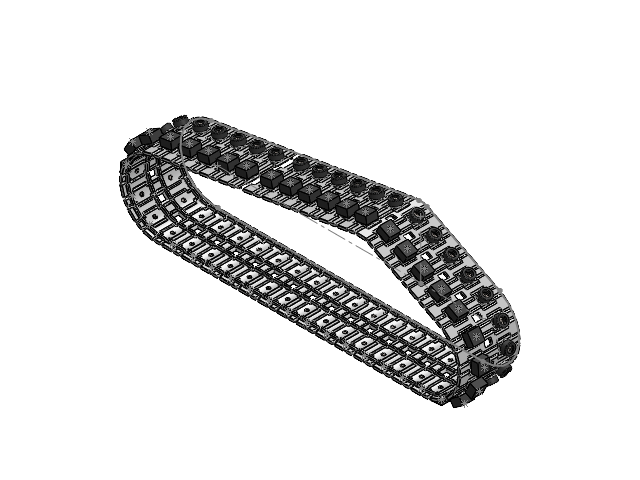
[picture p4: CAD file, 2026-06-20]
hardware/00_CAD/BG_Body/04_Kette/00_BG_Kette.SLDASM
A2000_Kettenglied_Profil_V2 x 40
A2000_Kettenglied_Stift_V2 x 80
A2000_Kettenglied_Antirutschmatte x 40
A2000_Kettengleid_Gummipuffer x 40
hex nut style 1 gradeab_din x 80
socket head cap screw 4762_din x 40
socket csink head cap screw 10642_din x 40
A2000_Kettenglied_Zahn_V2 x 40

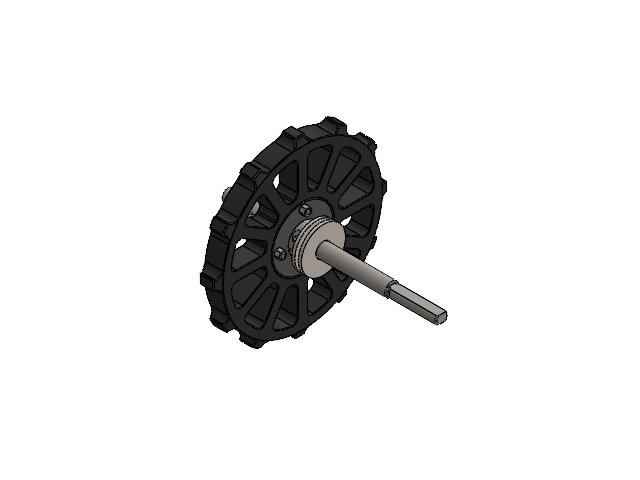
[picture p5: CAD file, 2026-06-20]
hardware/00_CAD/BG_Body/02_Vorne_hinten/03_Wellen_und_Antrieb/02_Passiver_Teil/01_Welle_Passiv/00_BG_Welle_Passiv.SLDASM
WA_Welle_Passiv
WA_Klemmring __12mm
thin flat keys gb
WA_Zwischenhülse Nadellager
WA_Nadellager-BLACKBOX
plain washer large_din x 2
WA_Antriebsrad_V2
WA_Antriebsrad_Buchse_Passfeder x 2
WA_M4x25_BA2 x 4
WA_HNTL1N-ST-M4 x 4
Abstandshülse_40mm_shell
RX-M4x8.1.step x 2
socket head cap screw_din x 2

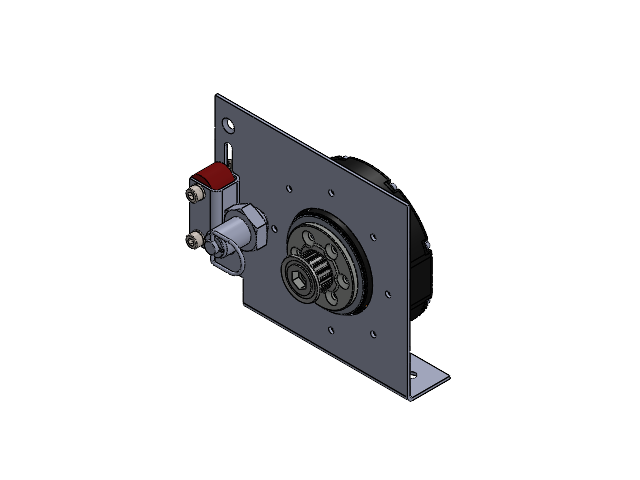
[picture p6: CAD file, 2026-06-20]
hardware/00_CAD/BG_Body/03_Flipper/02_Flippermotoren/00_BG_Flipper_Motor.SLDASM
FP_Motorhalterung_Flipper
FP_Unitree Motor GO
FP_U_Profil
FP_Rad
FP_Rohr
20251231gn_26411_01
20251231gn_26411_02
FP_gn_26411_04
socket head cap screw 4762_din x 2
FP_fath_096505 x 2
curved spring lock washer_din x 2
plain washer 6902 type abc_din x 4
20251231gn_26411_03
FP_Riemenrad_Motor

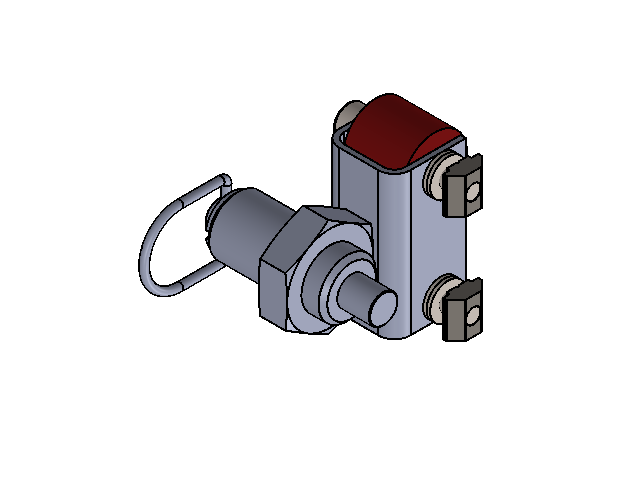
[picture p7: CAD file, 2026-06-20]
hardware/00_CAD/BG_Body/03_Flipper/04_Riemenspanner/BG_FP_Spanner.SLDASM
FP_U_Profil
FP_Rad
FP_Rohr
20251231gn_26411_01
20251231gn_26411_02
FP_gn_26411_04
socket head cap screw 4762_din x 2
FP_fath_096505 x 2
curved spring lock washer_din x 2
plain washer 6902 type abc_din x 4
20251231gn_26411_03

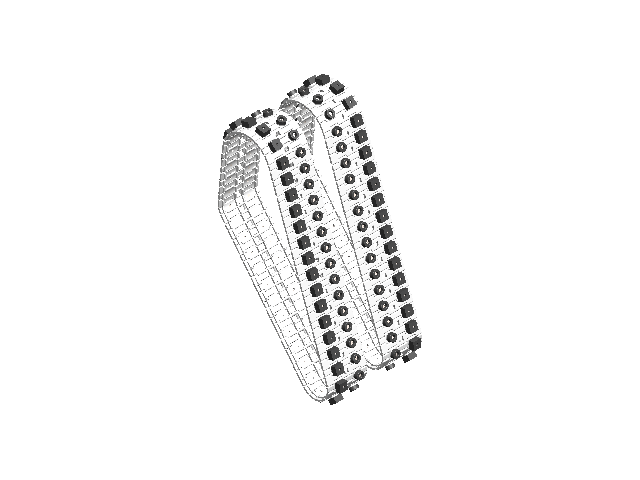
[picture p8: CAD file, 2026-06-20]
hardware/00_CAD/BG_Body/04_Kette/01_Kettenprofil_V3/A2000_Kettenglied_Baugruppe_V2.SLDASM
A2000_Kettenglied_Profil_V2 x 76
A2000_Kettenglied_Stift_V2 x 152
A2000_Kettenglied_Antirutschmatte x 76
A2000_Kettengleid_Gummipuffer x 76
hex nut style 1 gradeab_din x 152
socket head cap screw 4762_din x 76
socket csink head cap screw 10642_din x 76
A2000_Kettenglied_Zahn_V2 x 76

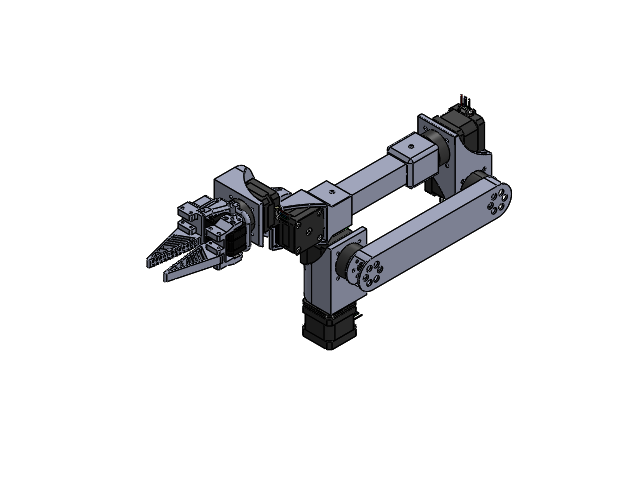
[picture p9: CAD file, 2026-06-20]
hardware/00_CAD/BG_Arm/00_BG_Arm.SLDASM
Aluprofil25x25
Aufsatz+90°
17HE08-1004S.step x 2
Aufsatz
17HE15-1504S.step x 4
Cricket_Drive_MK_II_d138fd89-5c7e-44b9-b403-75411b919790.step x 6
Halterung90°
Aluprofil40x20
Halterung90° + Aufsatz
Frontteil verstärkt - Kopie
Greifer x 2
Oberteil
Unterteil
ZK_122.step
SG-ZIJI_15.step
XG-ZIJI_16.step
MOTOR-1723_3.step
PCB-CHAZUO_92.step
GE_27.step
金属舵盘（驱动）.step
金属舵盘（从动）.step

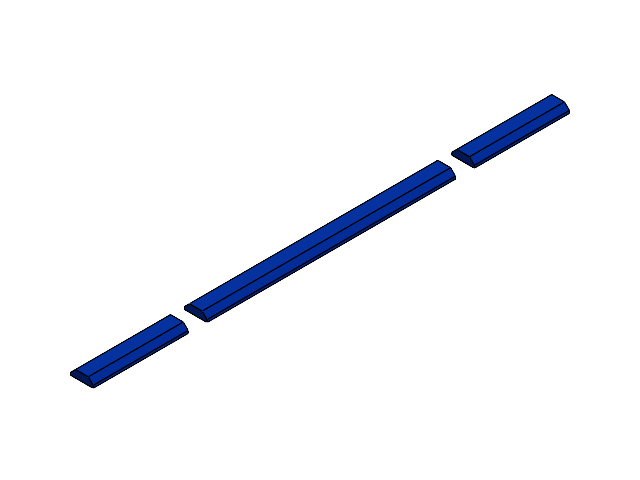
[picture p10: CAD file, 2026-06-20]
hardware/00_CAD/BG_Body/01_Mittelteil/Abstandshalter/MT_Abstand_Mini_PC.SLDASM
20251231Nutenstein_Abstandshalter (49,5mm) x 2
20251231Nutenstein_Abstandshalter (130mm)

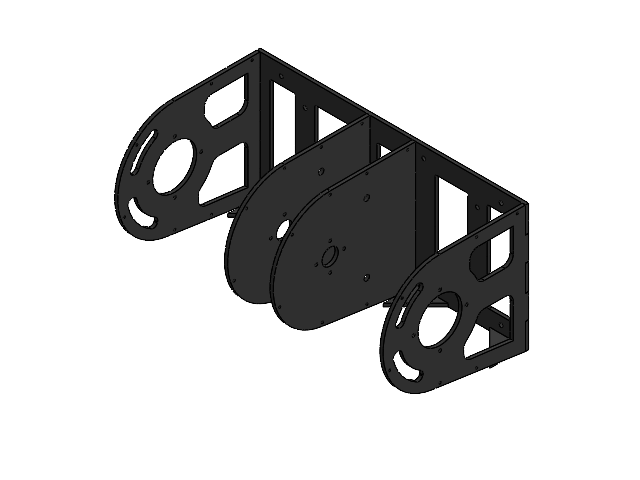
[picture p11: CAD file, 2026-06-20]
hardware/00_CAD/BG_Body/02_Vorne_hinten/02_Passives_E-Modul/00_BG_E-Passiv.SLDASM
EP_Rückplatte
EP_Mittelteil x 2
EA_EP_Außenteil x 2
EA_EP_Dreieick_verstärkung x 4

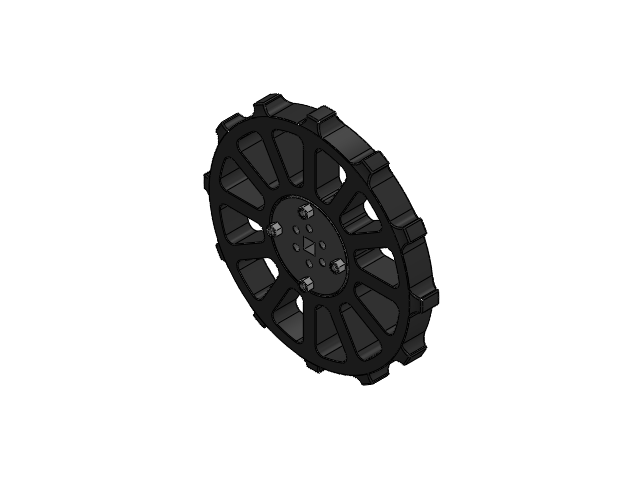
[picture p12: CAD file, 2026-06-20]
hardware/00_CAD/BG_Body/02_Vorne_hinten/03_Wellen_und_Antrieb/01_Aktiver_Teil/00_BG_Kettenantrieb_vierkant.SLDASM
WA_Antriebsrad_V2
WA_Antriebsrad_Buchse_Motor
WA_Antriebsrad_Buchse_Motor_vierkant
WA_M4x25_BA2 x 4
WA_HNTL1N-ST-M4 x 4

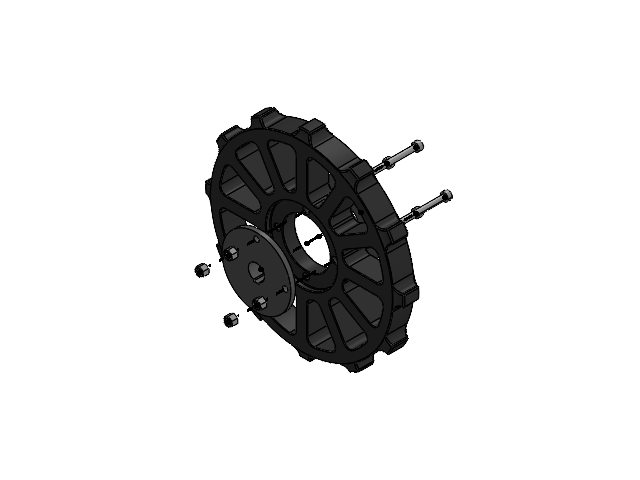
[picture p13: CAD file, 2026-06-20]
hardware/00_CAD/BG_Body/02_Vorne_hinten/03_Wellen_und_Antrieb/02_Passiver_Teil/01_Welle_Passiv/BG_Kettenantrieb_Passfeder.SLDASM
WA_Antriebsrad_V2
WA_Antriebsrad_Buchse_Passfeder x 2
WA_M4x25_BA2 x 4
WA_HNTL1N-ST-M4 x 4

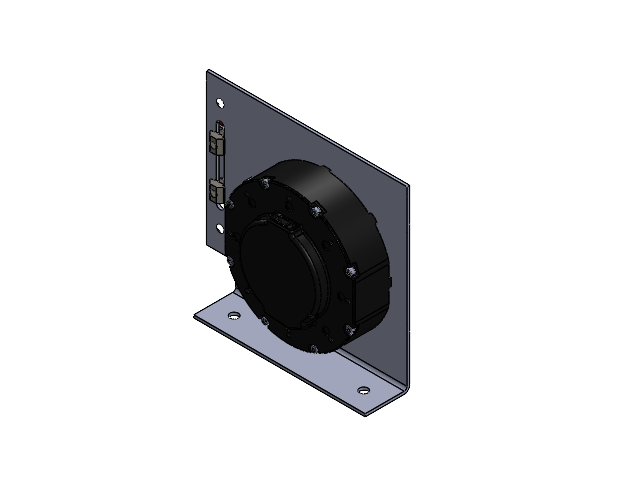
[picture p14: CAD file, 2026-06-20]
hardware/00_CAD/BG_Body/03_Flipper/02_Flippermotoren/00_BG_Flipper_Motor_gespiegelt.SLDASM
FP_Motorhalterung_Flipper_gespiegelt
FP_Unitree Motor GO
FP_U_Profil
20251231gn_26411_01
20251231gn_26411_02
FP_gn_26411_04
socket head cap screw 4762_din x 2
FP_fath_096505 x 2
curved spring lock washer_din x 2
plain washer 6902 type abc_din x 4
20251231gn_26411_03
FP_Rohr
FP_Rad
FP_Riemenrad_Motor

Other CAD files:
hardware/00_CAD/BG_Body/02_Vorne_hinten/03_Wellen_und_Antrieb/02_Passiver_Teil/02_Befestigung_Schrägkugellager/00_BK_Schraegkugellager.SLDASM
hardware/00_CAD/BG_Body/02_Vorne_hinten/03_Wellen_und_Antrieb/02_Passiver_Teil/03_Abstandshuelse_40mm/00_BK_Abstandshuelse_40mm.SLDASM
hardware/00_CAD/BG_Body/01_Mittelteil/Abstandshalter/00_BG_MT_Abstandshalter_Deckel_Arm.SLDASM
hardware/00_CAD/BG_Body/03_Flipper/03_Flipper_Welle/BG_ROBO_Welle_Führung Welle.SLDASM
hardware/00_CAD/BG_Arm/ARM_Aluprofil25x25.SLDPRT
hardware/00_CAD/BG_Arm/ARM_Aluprofil40x20.SLDPRT
hardware/00_CAD/BG_Arm/ARM_Aufsatz+90°.SLDPRT
hardware/00_CAD/BG_Arm/ARM_Aufsatz.SLDPRT
hardware/00_CAD/BG_Arm/ARM_Cricket_Drive_MK_II.step
hardware/00_CAD/BG_Arm/ARM_Frontteil.SLDPRT
hardware/00_CAD/BG_Arm/ARM_Greifer.SLDPRT
hardware/00_CAD/BG_Arm/ARM_Halterung90°+Aufsatz.SLDPRT
hardware/00_CAD/BG_Arm/ARM_Halterung90°.SLDPRT
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

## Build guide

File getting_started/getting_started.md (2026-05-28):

# Res.Q Bots Setup
Dieses Tutorial ist eine Schritt-für-Schritt Anleitung, um die komplette Softwaresuite des Res.Q Bots Teams einzurichten und mit dem Coden zu starten. Es werden keinerlei Vorkenntnisse benötigt.

**Disclaimer:**  
This REEADME is meant for internal use by Res.Q Bots members. While we do not forbid anyone else from using it, we want to caution you, that this file is not complete and updated infrequently. It is by no means a reliable source to work with, if you are not in direct contact with one of the people who have been working on it. Most of the packages used are open source packages developed by other people, who know what they are doing way better than us.
We have done our best to link to the original GitHubs for any non standard ROS packages.

<!-- ##################################################################################
#######################################################################################
#######################################################################################
#######################################################################################
####################################################################################-->
&nbsp;
# Inhalt
[Betriebssystem](#betriebssystem)   
[Ubuntu Grundlagen](#ubuntu-terminals)  
&nbsp;&nbsp;&nbsp;&nbsp; [Ubuntu Terminal Befehle](#wichtige-befehle)  
&nbsp;&nbsp;&nbsp;&nbsp; [ROS2 Befehle](#ros2-befehle)  
&nbsp;&nbsp;&nbsp;&nbsp; [Nützliche Programme](#nützliche-programme)  
[ROS2 Installieren](#ros2-installieren)  
[ROS2 Packages installieren und einrichten](#ros2-packages-installieren-und-einrichten)  
&nbsp;&nbsp;&nbsp;&nbsp; [Package Liste](#package-liste)  
&nbsp;&nbsp;&nbsp;&nbsp; [Steuerung](#steuerung)  
&nbsp;&nbsp;&nbsp;&nbsp; [Sensorik](#sensorik)  
&nbsp;&nbsp;&nbsp;&nbsp; [Lidar](#lidar-livox-mid-360)  
&nbsp;&nbsp;&nbsp;&nbsp; [Anzeige](#anzeige)  
&nbsp;&nbsp;&nbsp;&nbsp; [Development-Tools](#development-Tools)    
[Packages entwickeln](#packages-entwickeln)  
&nbsp;&nbsp;&nbsp;&nbsp; [Grundlagen](#grundlagen)  
&nbsp;&nbsp;&nbsp;&nbsp; [ros2_control Packages](#ros2_control-packages)  
&nbsp;&nbsp;&nbsp;&nbsp; []()  
&nbsp;&nbsp;&nbsp;&nbsp; []()  

<!-- TODO
	Links vervollständigen
 -->

<!-- ##################################################################################
#######################################################################################
#######################################################################################
#######################################################################################
####################################################################################-->
&nbsp;  
&nbsp;  
&nbsp;  
&nbsp;  
# Betriebssystem
Aktuell verwenden wir **Ubuntu 24.04 LTS** als OS, da dies die Basis für **ROS2 Jazzy** bildet.  

### Voraussetzungen
Internetverbindung  
USB Stick mit min 8 GB Speicher  

### Installation
Zuerst muss das **Ubuntu 24.04 Desktop** Image von der Ubuntu Website heruntergeladen werden.  
Danach ein Tool zum Erstellen eines USB-Startermediums installieren. z.B. **Rufus** oder **Balena-Etcher**  
Diese Tools haben auf ihren Webseites normalerweise Anleitungen, wie sie zu verwenden sind. Hier kann nicht viel falsch gemacht werden, solange **Ubuntu 24.04 Desktop** als image gewählt wird.

Für den PC im Roboter sollte die **Server** Variante des OS gewählt werden, da dieser ohne Bildschirm verwendet wird und dadurch Rechenleistung gespart werden kann, sowie die verwendung von **Remote-Tools** vereinfacht wird. 

<!-- ##################################################################################
#######################################################################################
#######################################################################################
#######################################################################################
####################################################################################-->
&nbsp;  
&nbsp;  
&nbsp;  
&nbsp;  
# Ubuntu Grundlagen
Ein sehr vereinfachtes und unvollständiges Intro in die **Linux Shell**, das den Umgang mit **Befehlsterminals** lehren und erklären soll.   
In Ubuntu lässt sich alles mit Terminalbefehlen erledigen. Gerade fürs Programmieren und den Umgang mit ROS ist es von enormer Bedeutung das Terminal nutzen zu können. 

&nbsp;
## Terminal UI
Die Tastenkombination `Strg`+`Alt`+`T` öffnet ein neues Terminal. Links in der aktuellen Zeile wird angezeigt, welcher **User** den Befehl ausführt, auf welchem **Host** der Befehl ausgeführt wird und in welchem **Verzeichnis** man sich gerade befindet, z.B.:

	resqbots@Q-T-Pi:~$ echo "hello world"

`resqbots` ist der **User**   

`Q-T-Pi` ist der **Host** ( = das Gerät auf dem der User angemeldet ist)

`~` ist das default Verzeichnis beim einloggen

`$` ist ein Trennsymbol, danach fängt der Befehl an

`echo "hello world"` ist der Befehl, der ausgeführt werden soll

&nbsp;
## Wichtige Befehle

### Strg + C
Die Tastenkombination `Strg` + `C` bricht den aktuell laufenden Prozess ab. Dies ist besonders wichtig, um ROS-Packages zu stoppen.

<!--################################################################################-->
&nbsp;
### cd
`cd <Verzeichnisname>` wechselt vom aktuellen Verzeichnis in das gewälte Unterverzeichnis. Mit `/` können mehrere Ebenen an Unterverzeichnissen aneinander gereiht werden. z.B.:

	cd ros_ws/src/resqbots_drive_interface/

Der Verzeichnisname `..` wechselt ein Verzeichnis nach "oben". So kommt man mit

	cd ..

wieder in das Verzeichnis `ros_ws/src/` und mit 

	cd ../..
wäre man im Verzeichnis `ros_ws`

Der Befehl `cd` ohne Verzeichnisnamen führt immer in das Standardverzeichnis zurück, egal wo man vorher war.

Das `~` Symbol ist ein Platzhalter für den "standard" Arbeitsbereich. Wenn man also beispielsweise aus dem Verzeichnis `lidar_ws/src` in das Verzeichnis `moveit2_ws/src` wechseln will, gelingt das mit:

	cd ~/moveit2_ws/src

<!--################################################################################-->
&nbsp;
### sudo
`sudo` steht kurz für "super user do" und entspricht dem **"Als Administrator ausführen"** bei Windows. Viele Befehle können nur mit dem Vorsatz `sudo` ausgeführt werden. Auch geschützte Dateien können nur mit `sudo` verändert werden.

<!--################################################################################-->
&nbsp;
### apt install
`apt install <Paketname>` wird quasi ausschließlich mit `sudo` gemeinsam verwendet und installiert das gewünschte Paket.

	sudo apt install hollywood

installiert das hollywood Paket. (Ein netter Scherz, wenn man unwissende beeindrucken will.)

<!--################################################################################-->
&nbsp;
### mkdir
`mkdir <Verzeichnisname>` erstellt das gewünschte Verzeichnis. 

	mkdir Test

erstellt das Verzeichnis `Test`

Der zusatz `-p` sorgt dafür, dass alle Übergeordneten Verzeichnisse unverändert bleiben. Mit `-p` können auch Unterverzeichnisse in einem Befehl mit-genereirt werden.

	mkdir -p ros_ws/src

erstellt das Verzeichnis `src` im Verzeichnis `ros_ws`. Falls das Verzeichnis `ros_ws` nicht existiert, wird es ebenfalls erstellt.

<!--################################################################################-->
&nbsp;
### rm
`rm <Dateiname>` wird eigentlich nur mit `sudo` davor verwendet. `sudo rm <Dateiname>` löscht die benannte Datei.
Mit dem zusatz `-r` können auch ganze Verzeichnisse gelöscht werden.

	sudo rm -r ros_ws

löscht den oben erstellten `ros_ws` und **alle Unterverzeichnisse**

<!--################################################################################-->
&nbsp;
### nano
`nano` ist eine Texteditor von Ubuntu. Damit können nahezu alle schreibbaren Dateiformate göffnet und bearbeitet werden. Für schreibgeschützte Dateien musst `sudo` vorgesetzt werden.  
Mit `nano <Dateiname>` wird die benannte Datei geöffnet, oder, falls sie nicht existiert, erstellt. Mit `sudo nano` erstellte Dateien sind für "normale" User schreibgeschützt und können nur mit `sudo` bearbeitet werden.

	sudo nano README.txt

erstellt z.B. eine schreibgeschützte `README.txt`.

<!--################################################################################-->
&nbsp;
### Tab
Mit der `Tab` Taste können befehle automatisch vervollstöndigt werden.  
Mit einem doppelten `Tab` werden alle verfügbaren Optionen angezeigt.

<!--################################################################################-->
&nbsp;
### ssh
`ssh user@host` stellt eine Remoteverbindung zum gewählten Gerät her und loggt sich als der genannte User ein. Der **Host** kann dabei druch die **IP-Adresse** oder den **Gerätenamen** mit dem zusatz `.local` angegeben werden.

	ssh resqbots@192.168.1.42

	ssh resqbots@q-t-pi.local

loggt sich z.B. als user **resqbots** auf unserem RaspberryPi namens **Q-T-Pi** ein.  

Für das wiederholte Einloggen auf dem gleichen Gerät, sollte mit

	ssh-keygen

ein **ssh public key** erstellt werden, der dann mit

	ssh-copy-id user@host

auf das Zielgerät kopiert wird. Dadurch ist bei der Verbindung mittels `ssh` kein Passwort mehr nötig und es können z.B. skripte geschrieben werden, die durch die Remoteverbindung arbeiten.

<!--################################################################################-->
&nbsp;
### pkill
`pkill` kann ausgeführte Programme und ROS Nodes beenden, wenn diese nicht auf `strg+c` reagieren.  

	pkill --signal 2 -f /Pfad/zu/install/Verzeichnis

`--signal 2` schickt ROS Nodes das standard Signal zum Runterfahren. Das ist der sanfteste Weg, eine Node zu beenden. (z.B. wenn das Fenster dazu geschlossen wurde, ohne die Node vorher zu schließen.)  
`-f /Pfad` gibt den Pfad zum `/install` Ordner des Prozesses an, der geschlossen werden soll.

<!--################################################################################-->
&nbsp;
### ./ + Dateiname 
`./<Dateiname>` führt das gewählte **Shell-Skript** aus, falls das möglich ist. In einem Skript können z.B. mehrere Befehle aneinander gereiht sein, oder Befehle mit vielen Optionen ausgeführt werden.  
**Shell-Skripte** sind durch die Endung `.sh` gekennzeichnet und beginnen mit der Zeile `#!/bin/bash`  

<!-- ##################################################################################
#######################################################################################
####################################################################################-->
&nbsp;  
## ROS2 Befehle

<!--################################################################################-->
### ros2 run & ros2 launch
`ros2` ist ähnlich wie `sudo` eine Vorsilbe, die der Shell sagt, dass sie das Programm mit der ROS2 Umgebung ausführen soll.  
`run` und `launch` sind zwei Varianten, Programme (Packages) in ROS zu starten. `run` startet das Programm in seiner einfachsten Form. `launch` startet das **launch file** des Packages und kann oft mit einer vielzahl von Optionen versehen werden.

	ros2 run joy joy_node

startet z.B. das ROS2-Standardprogramm für Controller (X-Box/Playstation/etc.). `joy` ist der Name des Programms, `joy_node` ist die Node (also die Funktion), die ausgeführt werden soll.

	ros2 launch tele_op operator.launch.py

startet unser `tele_op` Package und die `joy_node`. Im `operator.launch.py`-Launch-File steht, welche Nodes mit welchen Optionen gestartet werden sollen.  
Die meisten launch Befehle enden auf `.launch` und `.py` oder `.cpp`. `.launch` signalisiert, dass es sich um eine Launch-Datei handelt, `.py` zeigt, dass es eine **Python**-Datei ist, `.cpp` steht für **C++**.

<!--################################################################################-->
&nbsp;
### weitere ROS2 Befehle
`ros2 node list` -> Liste aktiver ROS Nodes  
`ros2 topic list` -> Liste aktiver ROS Topics  
`ros2 topic echo` -> Zeigt angegebenes Topic an  
`ros2 service list` -> Liste verfügbarer ROS Services  
`ros2 contol *` -> ale Befehle im zusammenhang mit ros2_control (Liste der Hardwareinterfaces/Controller, Status der Interfaces/Controller, etc)  
`ros2 run rqt_graph rqt_graph` -> Zeigt eine graphische Darstellung aller aktiven Nodes, Services, Topics, etc
`sudo apt install ros-jazzy-PackageName` -> installiert das genannte Package

<!-- ##################################################################################
#######################################################################################
####################################################################################-->
&nbsp;  
## Nützliche Programme
`network-manager` -> Netzwerk-Management  
`net-tools` -> Netzwerkadapter  
`iperf3` -> Netzwerkgeschwindigkeit  
`nmap` -> Geräte im Netzwerk finden

<!-- ##################################################################################
#######################################################################################
#######################################################################################
#######################################################################################
####################################################################################-->
&nbsp;  
&nbsp;  
&nbsp;  
&nbsp;
# ROS2 installieren
Wir verwenden auf unseren Rechnern `ROS2 Jazzy`. Für die Installation folgt am besten der [offiziellen ROS2 Jazzy Installationsanleitung](https://docs.ros.org/en/jazzy/Installation/Ubuntu-Install-Debs.html)

### ROS einrichten:
Alle Packages in Ros müssen **gesourced** werden, damit sie von der Shell gestartet werden können.
Um ein Package schnell in der aktuellen Shell zu sourcen kann der Befehl 

	source $package_ws$/install/setup.bash 

verwendet werden. Wobei `$package_ws$` durch den Pfad zum Ordner, in dem der `colcon-build` Befehl ausgeführt wurde, ersetzt werden muss. (z.B. ~/ros_ws) 
Falls man den `colcon-build` Befehl im aktuellen Ordner verwendet hat, reicht `source install/setup.bash`.

Um ein Package permanent zu sourcen muss der Befehlt in die **~/.bashrc** Datei geschrieben werden. Das ist eine Setup Datei, die der Shell sagt, was sie vor dem Start alles machen muss. (z.B. ROS sourcen, oder die Hintergrundfarbe ändern.) 

	echo "source /opt/ros/jazzy/setup.bash" >> ~/.bashrc

Die **DOMAIN_ID** sagt ROS welche Geräte in deinem Netzwerk zur gleichen Gruppe gehören. Sie ist per Default auf **0**, kann aber verändert werden. Wir haben sie aus Spaß und zur Sicherheit auf **17** gelegt. 
Auch das muss in der Shell eingestellt werden:

	echo "export ROS_DOMAIN_ID=17" >> ~/.bashrc

**rosdep** ist ein Verzeichnis in dem viele Packages über alle aktiven ROS Distros hinterlegt sind. Manchmal hilft es, das **rosdep** zur Verfügung zu haben.

	sudo rosdep init && rosdep update

Zuletzt sollte ein **Workspace** erstellt werden, in dem an eigenen Packages gearbeitet werden kann:

	cd && mkdir -p ros_ws/src

Grundsätzlich werden ROS Packages, die nicht einfach per `sudo apt install` installiert werden können in **Workspaces** gespeichert und gebuildet, damit das Dateimanagement vereinfacht wird. Die Workspaces sinnvoll zu benennen ist dabei von Vorteil.

<!-- ##################################################################################
#######################################################################################
#######################################################################################
#######################################################################################
####################################################################################-->
&nbsp;  
&nbsp;  
&nbsp;  
&nbsp;  
# ROS2 Packages installieren und einrichten
Packages sind Programme, die im ROS2 Framework ausgeführt werden können. Für die meisten Funktionen eines Roboters gibt es bereits fertige Packages. Bei einigen müssen nur geringere Einstellungen angepasst werden, um sie mit unserem Roboter zu verwenden, andere müssen stärker angepasst werden. Falls ein eigenes Package geschrieben werden muss, kann aber auch dabei auf Grundbausteine aus der ROS2 Bibliothek zurückgegriffen werden.

### Package-Liste
&nbsp; &nbsp; **Comunity Packages**   
&nbsp; &nbsp; &nbsp; &nbsp; [**Steuerung**](#steuerung)  
&nbsp; &nbsp; &nbsp; &nbsp; [joy](#joy) -> liest Controllerdaten aus   
&nbsp; &nbsp; &nbsp; &nbsp; [robot_state_publisher](#robot-state-publisher) -> zeigt Position und Lage des Roboters an  
&nbsp; &nbsp; &nbsp; &nbsp; [ros2_control und ros2_controllers](#ros2_control-und-ros2_controller) -> Motoren ansteuern und Feedback einholen  
&nbsp; &nbsp; &nbsp; &nbsp; [moveit2](#moveit2) -> Armkinematik  
  
&nbsp; &nbsp; &nbsp; &nbsp; [**Sensorik**](#sensorik)  
&nbsp; &nbsp; &nbsp; &nbsp; [audio_common](#audio_common) -> Micro und Lautsprecher  
&nbsp; &nbsp; &nbsp; &nbsp; [camera_ros]() -> USB Kamera Interface

&nbsp; &nbsp; &nbsp; &nbsp; [**LiDAR**](#lidar-livox-mid-360)  
&nbsp; &nbsp; &nbsp; &nbsp; [Livox_SDK2](#livox_sdk2)-> LiDAR Interface  
&nbsp; &nbsp; &nbsp; &nbsp; [livox_ros_driver2](#livox_ros_driver2) -> LiDAR Interface  
&nbsp; &nbsp; &nbsp; &nbsp; [PCL](#pcl) -> support für Fast_LIO2  
&nbsp; &nbsp; &nbsp; &nbsp; [Eigen](#eigen3) -> support für Fast_LIO2   
&nbsp; &nbsp; &nbsp; &nbsp; [Fast_LIO2](#fast_lio2) -> LiDAR Mapping  
&nbsp; &nbsp; &nbsp; &nbsp; [nav2_map_server](#nav2_map_server) -> speichert LiDAR Karten

&nbsp; &nbsp; &nbsp; &nbsp; [**Anzeige**](#anzeige)  
&nbsp; &nbsp; &nbsp; &nbsp; [rviz2]() -> LiDAR Karte und robot_state  
&nbsp; &nbsp; &nbsp; &nbsp; [rqt_image_view]() -> zeigt Kamerabilder an  

&nbsp; &nbsp; &nbsp; &nbsp; **Support Packages**  
&nbsp; &nbsp; &nbsp; &nbsp; v4l2  
&nbsp; &nbsp; &nbsp; &nbsp; image-transport-plugins  
&nbsp; &nbsp; &nbsp; &nbsp; ioport  

&nbsp; &nbsp; &nbsp; &nbsp; [**Development-Tools**](#development-tools)  
&nbsp; &nbsp; &nbsp; &nbsp; [xacro]()  
&nbsp; &nbsp; &nbsp; &nbsp; [joint_state_publisher_gui]()  
&nbsp; &nbsp; &nbsp; &nbsp; []()  

&nbsp; &nbsp; **Eigene Packages**   
&nbsp; &nbsp; &nbsp; &nbsp; [lotti2_teleop]() -> verteilt User Input an die ros2_controller  
&nbsp; &nbsp; &nbsp; &nbsp; [lotti2_control]() -> ros2_control Package für den "Lotti" Roboter. Enthält das Robotermodell, Infos über alle Motoren und die Interfaces um diese anzusteuern.  
&nbsp; &nbsp; &nbsp; &nbsp; [lotti2_flipper_controller]() -> Wandelt User Input in Motorbefehle um.  

<!-- ##################################################################################
#######################################################################################
####################################################################################-->
&nbsp;  
&nbsp;  
## Steuerung

### joy
`joy` liest die Befehle eines standard Spielecontrollers aus und published sie im Topic `/joy`.  
`joy` ist normalerweise bereits in der ROS2 Basisinstallation enthalten. Falls `joy` aus irgendeinem Grund nicht direkt nach der ROS2 Installation läuft, kann es, wie alle Basispackages, nachträglich installiert werden.

	sudo apt install ros-jazzy-joy

<!--################################################################################-->
&nbsp;  
### robot state publisher
Der `robot_state_publisher` ist eine Node, die den aktuellen Status des Roboters published. Das ist notwendig für komplexere Bewegungsbefehle und zur visualisierung des Roboters. Der `robot_state_publisher`alleine tut nicht viel, ist aber ein notwendiger Bestandteil der ros2_control Arbeitskette.

	sudo apt install ros-jazzy-robot-state-publisher

<!--################################################################################-->
&nbsp;
### ros2_control und ros2_controller
Für die Steuerung des Roboters verwenden wir `ros2_control`. Das ist eine mächtige Controller-Interface Kombination, die extra für die Steuerung von Roboter entwickelt wurde. Für tiefere Einblicke in die Verwendung ist am besten eines der verlinkten Tutorials geeignet.

`ros2_control` und `ros2_controller` sind standard Packages in ROS2 und können nur gemeinsam verwendet werden, daher sollte man immer beide installieren.

	sudo apt install ros-jazzy-ros2-control ros-jazzy-ros2-controllers

<!--################################################################################-->
&nbsp;  
### Moveit2
`Moveit2` enthält mächtige Tools für inverse Kinematiken. Wir nutzen dieses Package um unseren Arm zu steuern.  
Auch, wenn nicht alle Komponenten von `Moveit2` benötigt werden, lohnt es sich alle zu installieren, damit sie zur Verfügung stehen.

    sudo apt install ros-jazzy-moveit*

<!-- ##################################################################################
#######################################################################################
####################################################################################-->
&nbsp;  
&nbsp;  
&nbsp;  
&nbsp;  
## Sensorik

### audio_common
Dieses Setup ermöglicht die Audio-Kommunikation über ROS 2 Humble zwischen einem Laptop und einem Raspberry Pi – in beide Richtungen:  
Laptop → Raspberry Pi (Audioaufnahme am Laptop, Wiedergabe am Pi)  
Raspberry Pi → Laptop (Audioaufnahme am Pi, Wiedergabe am Laptop)

**Installation: Audio-Tools und Dev-Packages**

	sudo apt install -y 
  	libasound2-dev 
  	gstreamer1.0-plugins-base 
 	libgstreamer1.0-dev 
 	liborc-0.4-dev 
  	libdw-dev libelf-dev libunwind-dev
	espeak alsa-utils pavucontrol

**ROS2 Workspace einrichten - auf BEIDEN Geräten!**

	mkdir -p ~/ros2_audio_ws/src
	cd ~/ros2_audio_ws/src
	git clone -b ros2 https://github.com/ros-drivers/audio_common.git

**Abhängigkeiten & Workspace bauen**

	cd ~/ros2_audio_ws
	rosdep install --from-paths src --ignore-src -r -y
	colcon build --symlink-install

**Kommunikation Raspberry Pi → Laptop**

**Raspberry Pi (Sender)**

	export AUDIODEV=plughw:1,0
	source ~/ros2_audio_ws/install/setup.bash
	ros2 run audio_capture audio_capture_node --ros-args -r __node:=capture_pi

**Laptop (Empfänger)**

	source ~/ros2_audio_ws/install/setup.bash
	ros2 run audio_play audio_play_node --ros-args -r __node:=play_laptop

**Verifikation & Tests**

**Verbindung prüfen (z. B. auf dem Pi):**

	ros2 topic info /audio
	
**Erwartete Ausgabe:**

	Type: audio_common_msgs/msg/AudioData
	Publisher count: 1
	Subscription count: 1

**Live-Daten anzeigen:**

	ros2 topic echo /audio

**Testausgabe senden (z. B. am Laptop):**

	espeak "Hallo Raspberry" --stdout | aplay

<!--################################################################################-->
&nbsp;
### camera_ros
Wir verwenden das `camera_ros` Package für unsere USB Kameras.  
Da `camera_ros` ein Standardpackage von `humble` ist, gestaltet sich die Installation ganz einfach:

	sudo apt install ros-jazzy-camera-ros

Die Einstellungen für die individuellen Kameras werden in `.yaml` Dateien festgehalten.  

<!-- TODO
	-besipiel .yaml datei
	-erklärung der Parameter
	-erklärung, wie kamera gestartet und .yaml geladen wird 
	-->

<!-- ##################################################################################
#######################################################################################
####################################################################################-->
&nbsp;  
&nbsp;  
&nbsp;  
&nbsp;  
## LiDAR: Livox MID 360
Wir arbeiten mit dem **Livox MID 360** LiDAR. Um diesen nutzen zu können müssen auf dem Gerät, das die Daten vom LiDAR auslesen soll die Packages `Livox_SDK2`  und `livox_ros_driver2` installiert sein.
Um die Daten vom LiDAR zu einer Karte zu verarbeiten, verwenden wir `Fast_LIO2`. Das wiederum benötigt `Eigen3` und `PCL` um zu funktionieren.

Die Links zu den Originalprogrammen findet ihr hier:  
**Livox_SDK2:** https://github.com/Livox-SDK/Livox-SDK  
**Fast_LIO2:** https://github.com/hku-mars/FAST_LIO2  
**livox_ros_driver2:** https://github.com/Livox-SDK/livox_ros_driver2  

&nbsp;  
Vor der Installation sollte ein **Workspace** für die Livox Packages erstellt werden:

	cd  && mkdir -p livox_ws/src 

<!--################################################################################-->
&nbsp;  
### Livox_SDK2
Das GitHub Repo der **SDK** in den **Workspaca** kopieren

	cd ~/livox_ws/src
	git clone https://github.com/Livox-SDK/Livox-SDK2.git
	
Da die **SDK** ursprünglich für frühere ROS Versionen entwickelt wurde müssen vor dem builden noch Änderungen vorgenommen werden. Dazu wird die Zeile `#include <cstdint>` in den Bereichen mit den anderen `#include` Zeilen in den Dateien `sdk_core/comm/define.h` und `sdk_core/logger_handler/file_manager.h`  eingefügt: 

	cd Livox-SDK2
	nano sdk_core/comm/define.h
	nano sdk_core/logger_handler/file_manager.h
	
Danach ist das Package bereit für den build-Prozess:

	mkdir build && cd build
	cmake ..
	make -j

Nach die Umsetzung des Befehls `make -j` dauert extrem lang und beim RaspberryPi hängt sich wahrscheinlich die ssh Verbindung auf. Nicht wundernn, einfach das Terminal schließen und nach ca. 15 Minuten neu verbinden und weiter machen. 

**Fals Verbindung abgebrochen**

ssh aufbauen, dann 
	
	cd livox_ws/src/Livox-SDK2/build

**weiter builden**

	sudo make install

Auch der build-Prozess dauer ewig, nicht wundern. `Livox_SDK2` ist nur ein support Package für `livox_ros_driver2` und muss nicht gesourced werden.

<!--################################################################################-->
&nbsp;  
### livox_ros_driver2 
Das GitHup Repo in den **Workspace** kopieren

	cd ~/livox_ws/src
	git clone https://github.com/Livox-SDK/livox_ros_driver2.git

und dann builden

	cd livox_ros_driver2
	./build.sh humble

Der Parameter `humble` funktioniert auch bei humble, das Package ist einfach etwas älter.

Nach dem erfolgreichen Builden das Package sourcen:

	source ~/livox_ws/install/setup.bash
	echo "source ~/livox_ws/install/setup.bash" >> ~/.bashrc

<!--################################################################################-->
&nbsp;  
### PCL
PCL ist eine Support-Suite, die viele Mathematische Prozesse im Bezug auf Punktewolken übernimmt.
Sie ist einfach zu installieren:

	sudo apt update
	sudo apt install pcl-*
	sudo apt install libpc-dev libpcl-ros-dev

<!--################################################################################-->
&nbsp;  
### Eigen3 
Eigen ist eine Sammlung an Header-Files, die den build Prozess anderer Packages unterstützen kann. Sie wird benötigt um `Fast_LIO2` builden zu können.

Für Eigen sollte ein extra **Workspace** erstellt werden, da es sonst zu ungewollten interaktionen mit anderen Packages kommen könnte. Der restliche Installationsprozess läuft wie immer ab.

	git clone https://gitlab.com/libeigen/eigen.git
	cd eigen
	mkdir build && cd build
	cmake ..
	make -j
	sudo make install

Auch hier ist ein **sourcen** nicht nötig.

<!--################################################################################-->
&nbsp;  
### Fast_LIO2
Zu guter Letzt kann endlich `Fast_LIO2` installiert werden.

`Fast_LIO2` ist ein Package, das LiDAR Daten zu einer Karte zusammenfügen kann, ohne dafür **Odometry** Daten zu benötigen, indem es ähnlich dem Menschen "versteht" , dass sich Wände nicht bewegen, sonder der LiDAR selbst. (Nur mit deutlich mehr Mathe dahinter.)

Auch für `Fast_LIO2` wird ein eigener **Workspace** erstellt, das das Package wieder lang zum builden braucht und nicht versehentlich neu gebuildet werden sollte, wenn man nur ein eigenes Package testen will.

	cd  && mkdir -p fast_lio2_ws/src
	cd fast_lio2_ws/src
	git clone https://github.com/Ericsii/FAST_LIO2_ROS2.git --recursive
	cd ..
	rosdep install --from-paths src --ignore-src -y

Nachdem das GitHub Repo in den **Workspace** kopiert und durch `rosdep install` erweitert wurde, muss noch die `CMakeLists.txt` Datei überarbeitet werden um mit der neuen ROS Version zu funktionieren.

	nano src/FAST_LIO2_ROS2/CMakeLists.txt

Und an allen Stellen das **c++14** und **c++17** durch **c++20** ersetzen.

Danach kann das Package mit `colcon` gebaut und im Anschluss gesourced werden.

	colcon build --symlink-install
	source install/setup.bash
	echo "source ~/fast_lio2_ws/install/setup.bash" >> ~/.bashrc

Falls das Package auf einem Gerät installiert wurde, das selbst nicht live die erstellte Karte anzeigen soll muss noch die **launch-Datei** angepasst werden.

	nano install/fast_lio2/share/fast_lio2/launch/mapping.launch.py

Die Zeile `ld.add_action(rviz_node)` mit **#** auskommentieren.

<!--################################################################################-->
&nbsp;  
### Nav2_map_server
`Nav2` ist eine Package Suite für die Roboternavigation. Das Subsystem `nav2_map_server` verwenden wir, um die in Fast_LIO2 erstellten Karten zu speichern.

**Installation:**

	sudo apt update
	sudo apt install ros-jazzy-nav2-map-server

Der Nav2_map_server wird beim Start von Fast_LIO2 automatisch mit gestartet.

<!--################################################################################-->
&nbsp;  
&nbsp;  
### LiDAR Einrichten
Um den Lidar verwenden zu können müssen noch ein paar Schritte erledigt werden.

Die `livox_ros_driver2` kann nur mit **statischen IP Adressen** arbeiten. Daher muss im Gerät, das die LiDAR Daten auslesen soll, **DHCP** ausgeschaltet werden. Mit

	cd /etc/netplan/
	ls

werden alle Dateien im Verzeichnis `netplan` angezeigt. Normalerweise ist es nur eine, die `50-cloud-init.yaml` oder so ähnlich heißt. Diese `.yaml` Dateien sind schreibgeschützt, müssen also mit `sudo` geöffnet werden.

	sudo nano <Dateiname>

Das Terminal sollte nun ca. so aussehen:

	network:
		wifis:
			wlan0:
				dhcp4: true

Unter dem Existierenden Abschnitt für `wifis` den folgenden Abschnitt einfügen:

	ethernets:
        eth0:
            dhcp4: false
            addresses:
            - 192.168.1.50/24
            optional: true

Nach dem Speichern und Verlassen der Datei müssen die Änderungen übernommen werden:

	sudo netplan apply

Jetzt hat das Gerät eine **statische IP** von 192.168.1.50 im **Ethernet**. Das Gerät kann jetzt nicht mehr über Ethernet angesteuert werden. Wird das benötigt, einfach das `dhcp4: false` durch `dhcp4: true` ersetzen.

Jetzt muss in der **Konfig-Datei** die **IP Adresse** festgehalten werden.
Der Befehlt

	nano livox_ws/install/livox_ros_driver2/share/livox_ros_driver2/config/MID360_config.json 

zeigt die `MID360_config.json` Datei. Sie sieht nach der ersten Installation wie folgt aus:

<pre>
{
"lidar_summary_info" : {
	"lidar_type": 8
},
"MID360": {
	"lidar_net_info" : {
	"cmd_data_port": 56100,
	"push_msg_port": 56200,
	"point_data_port": 56300,
	"imu_data_port": 56400,
	"log_data_port": 56500
	},
	"host_net_info" : {
	"cmd_data_ip" : "192.168.1.5",
	"cmd_data_port": 56101,
	"push_msg_ip": "192.168.1.5",
	"push_msg_port": 56201,
	"point_data_ip": "192.168.1.5",
	"point_data_port": 56301,
	"imu_data_ip" : "192.168.1.5",
	"imu_data_port": 56401,
	"log_data_ip" : "",
	"log_data_port": 56501
	}
},
"lidar_configs" : [
	{
	"ip" : "192.168.1.12",
	"pcl_data_type" : 1,
	"pattern_mode" : 0,
	"extrinsic_parameter" : {
		"roll": 0.0,
		"pitch": 0.0,
		"yaw": 0.0,
		"x": 0,
		"y": 0,
		"z": 0
	}
	}
]
}
</pre>

Im Abschnitt `"MID360":` überall die **IP Adresse** `192.168.1.5` durch die `192.168.1.50` ersetzen. 

Im Abschnitt `"lidar_configs" :` kann die **IP Adresse** des LiDARS eingestellt werden. Um diese zu erfahren, den LiDAR mit einem Netzwerk verbinden, einen PC mit dem gleichen Netzwerk verbinden und

	sudo apt update && sudo apt install nmap
	ip a 	#zeigt deine IP Adresse
	nmap <deine IP Adresse> 	# nur die letzte Zahl ersetzen durch 0/24 

In der Liste sollte irgendwo der LiDAR auftauchen. Die **Default IP** unseres LiDARs ist `192.168.1.196`. 

<!--################################################################################-->
&nbsp;  
### Lidar Optionen
In der Datei `*/src/FAST_LIO2_ROS2/config/mid360.yaml` können Einstellungen für den LiDAR Betrieb vorgenommen werden. `*` steht für die übergeordneten Verzeichnisse. In unserem Fall wahrscheinlich `~/fast_lio2_ws`

	nano ~/fast_lio2_ws/src/FAST_LIO2_ROS2/config/mid360.yaml

Gibt folgendes aus:

<pre>
/**:
	ros__parameters:
		feature_extract_enable: false
		point_filter_num: 3
		max_iteration: 3
		filter_size_surf: 0.5
		filter_size_map: 0.5
		cube_side_length: 1000.0
		runtime_pos_log_enable: false
		map_file_path: "./test.pcd"

		common:
			lid_topic:  "/livox/lidar"
			imu_topic:  "/livox/imu"
			time_sync_en: false         # ONLY turn on when external time synchronization is really >
			time_offset_lidar_to_imu: 0.0 # Time offset between lidar and IMU calibrated by other al>
										# This param will take effect no matter what time_sync_en is>

		preprocess:
			lidar_type: 1                # 1 for Livox serials LiDAR, 2 for Velodyne LiDAR, 3 for ou>
			scan_line:  4
			blind: 0.5
			timestamp_unit: 3
			scan_rate: 10

		mapping:
			acc_cov: 0.1
			gyr_cov: 0.1
			b_acc_cov: 0.0001
			b_gyr_cov: 0.0001
			fov_degree:    360.0
			det_range:     100.0
			extrinsic_est_en:  true      # true: enable the online estimation of IMU-LiDAR extrinsic
			extrinsic_T: [ -0.011, -0.02329, 0.04412 ]
			extrinsic_R: [ 1., 0., 0.,
							0., 1., 0.,
							0., 0., 1.]

		publish:
			path_en: true                # true: publish Path
			effect_map_en: false         # true: publish Effects
			map_en: true                 # true: publish Map cloud
			scan_publish_en:  true       # false: close all the point cloud output
			dense_publish_en: false      # false: low down the points number in a global-frame point>
			scan_bodyframe_pub_en: true  # true: output the point cloud scans in IMU-body-frame

		pcd_save:
			pcd_save_en: true
			interval: -1                 # how many LiDAR frames saved in each pcd file; 
										# -1 : all frames will be saved in ONE pcd file, may lead to>
</pre>

Bei `map_file_path:` den gewünschten Pfad + Dateinamen eingeben z.B. `"~/maps/latest_map.pcd"`

`scan_rate:` kann auf 10, 30, 50 oder 100 gesetzt werden und steht für die Abtastrate des LiDAR. **Vorsicht:** je höher die `scan_rate` desto mehr Rechenleistung wird für die Karte benötigt und desto schneller füllt sich der Arbeitsspeicher.

<!--################################################################################-->
&nbsp;  
&nbsp;  
### Lidar verwenden
**Lidar Starten**  
Auf dem Laptop im Terminal im `/home directory`

	./lidar_launch.sh	

eingeben, für automatischen Start.  
Oder auf dem Mini PC 2 Terminals öffnen

	Terminal1: ros2 launch livox_ros_driver2 msg_MID360_launch.py
	Terminal2: ros2 launch fast_lio2 mapping.launch.py config_file:=mid360.yaml

**Karte speichern**

Automatisch im Laptopterminal `/home directory` mit 

	/.save_map.sh
es erscheint nun eine Meldung im Terminal:

	waiting for service to become available...
	requester: making request: std_srvs.srv.Trigger_Request()

und kurz darauf folgt:
	
	response:

	std_srvs.srv.Trigger_Response(success=True, message='Map saved.')
in diesem Fall war das speichern erfolgreich.  

Falls nach einigen Sekunden keine weitere Nachricht folgt, ist ein Fehler aufgetreten.  
Die einfachsten möglichen Ursachen sind:  
- Das Lidar Programm läuft nicht  
- Die Verbindung zum MiniPC ist unterbrochen  
- Der map_saver_server läuft nicht  

<!-- ##################################################################################
#######################################################################################
####################################################################################-->
&nbsp;  
&nbsp;  
&nbsp;  
&nbsp;  
## Anzeige

### rviz2  
Das Modell des Roboters und die aktuelle Lidar Karte visualisieren wir mit `rviz2`.

	sudo apt install ros-jazzy-rviz2

<!--################################################################################-->
&nbsp;  
### rqt_image_view  
Für die Anzeige der Kamerabilder verwenden wir `rqt_image_view`. Es ist Teil der `rqt`-Suite, die für viele Funktionen in ROS2 hilfreich ist. Sie sollte bei der ROS Basisinstallation bereits heruntergeladen sein. Falls nicht kann entweder nur `rqt_image_view` oder die gesamte rqt-Suite installiert werden:

	sudo apt install ros-jazzy-rqt-image-view
	
	sudo apt install-ros-jazzy-rqt-*

<!-- ##################################################################################
#######################################################################################
####################################################################################-->
&nbsp;  
&nbsp;  
&nbsp;  
&nbsp;  
## Development-Tools

### xacro
`xacro` ist eine Erweiterung, die es erlaubt, eine `.URDF` auf mehrere Dateien aufzuteilen. Für mehr Infos siehe Abschnitt [URDF](#urdf). `xacro` ist kein ROS2 Package und muss deshalb installiert werden.

	sudo apt install ros-jazzy-xacro

<!--################################################################################-->
&nbsp;  
### joint_state_publisher_gui
Das `joint_state_publisher_gui` startet ein graphisches Interface mit Schiebereglern für alle momentan gepublishten Joints. Durch verschieben der Regler wird der Zustand des Joints angepasst. Dieses Tool hilft beim testen einer neuen oder angepassten `URDF` und hilft bei der Fehlersuche, falls ein Robotermodell nicht wie gedacht funktioniert.

	sudo apt install ros-jazzy-joint-state-publisher-gui

<!--################################################################################-->
&nbsp;  
### ros2_control_cmake
Dieses Package wird benötigt um ros2_control packages zu builden.

<!-- ##################################################################################
#######################################################################################
#######################################################################################
#######################################################################################
####################################################################################-->
&nbsp;  
&nbsp;  
&nbsp;  
&nbsp;  
# Packages entwickeln

### Grundlagen
Um von Null an zu lernen, wie man ein ROS2 Package entwickelt sollten die [Tutorials](https://docs.ros.org/en/humble/Tutorials.html) der ROS2 Dokumentation abgearbeitet werden. Danach sind die Basics klar(er) und es kann mit der Entwicklung komplexerer Programme fortgefahren werden.

<!-- ##################################################################################
#######################################################################################
####################################################################################-->
&nbsp;  
## ros2_control Packages

<!-- TODO
	Einleitung in ros2_control
	Tutorials verlinken
 -->

Für ros2_control Packages ist eine gewisse Ordnerstruktur notwendig, damit das System alle Komponenten findet. Der folgende Block zeigt eine Beispielstruktur, in der jede Enrückung eine niedrigere Ordnerebene darstellt. Bezeichnungen ohne Dateiendung sind Ordner. Die Funktionen und der Inhalt der jeweiligen Ordner werden im Verlauf des Kapitels genauer erklärt. Die wichtigsten Segmente sind mit Links versehen. 

Package_name  
&nbsp; &nbsp; &nbsp; &nbsp; bringup  
&nbsp; &nbsp; &nbsp; &nbsp; &nbsp; &nbsp; &nbsp; &nbsp; config  
&nbsp; &nbsp; &nbsp; &nbsp; &nbsp; &nbsp;  &nbsp; &nbsp; &nbsp; &nbsp; [controllers.yaml](#controllers.yaml)  
&nbsp; &nbsp; &nbsp; &nbsp; [launch](#launch-file-erstellen)  
&nbsp; &nbsp; &nbsp; &nbsp; &nbsp; &nbsp; full.launch.py  
&nbsp; &nbsp; &nbsp; &nbsp; &nbsp; &nbsp; teil.launch.py  
&nbsp; &nbsp; &nbsp; &nbsp; &nbsp; &nbsp; ...  
&nbsp; &nbsp; &nbsp; &nbsp; description  
&nbsp; &nbsp; &nbsp; &nbsp; &nbsp; &nbsp; &nbsp; &nbsp; meshes  
&nbsp; &nbsp; &nbsp; &nbsp; &nbsp; &nbsp; &nbsp; &nbsp; &nbsp; &nbsp; &nbsp; &nbsp; link1.stl  
&nbsp; &nbsp; &nbsp; &nbsp; &nbsp; &nbsp; &nbsp; &nbsp; &nbsp; &nbsp; &nbsp; &nbsp; link2.stl  
&nbsp; &nbsp; &nbsp; &nbsp; &nbsp; &nbsp; &nbsp; &nbsp; &nbsp; &nbsp; &nbsp; &nbsp; link3.stl  
&nbsp; &nbsp; &nbsp; &nbsp; &nbsp; &nbsp; &nbsp; &nbsp; &nbsp; &nbsp; &nbsp; &nbsp; ...  
&nbsp; &nbsp; &nbsp; &nbsp; &nbsp; &nbsp; &nbsp; &nbsp; [ros2_control](#ros2_controlxacro)  
&nbsp; &nbsp; &nbsp; &nbsp; &nbsp; &nbsp; &nbsp; &nbsp; &nbsp; &nbsp; &nbsp; &nbsp; ros2_control.xacro  
&nbsp; &nbsp; &nbsp; &nbsp; &nbsp; &nbsp; &nbsp; &nbsp; [srdf](#srdf)  
&nbsp; &nbsp; &nbsp; &nbsp; &nbsp; &nbsp; &nbsp; &nbsp; &nbsp; &nbsp; &nbsp; &nbsp; srdf_arm.xacro  
&nbsp; &nbsp; &nbsp; &nbsp; &nbsp; &nbsp; &nbsp; &nbsp; &nbsp; &nbsp; &nbsp; &nbsp; srdf_body.xacro  
&nbsp; &nbsp; &nbsp; &nbsp; &nbsp; &nbsp; &nbsp; &nbsp; &nbsp; &nbsp; &nbsp; &nbsp; ...  
&nbsp; &nbsp; &nbsp; &nbsp; &nbsp; &nbsp; &nbsp; &nbsp; [urdf](#urdf)  
&nbsp; &nbsp; &nbsp; &nbsp; &nbsp; &nbsp; &nbsp; &nbsp; &nbsp; &nbsp; &nbsp; &nbsp; Robot.urdf.xacro  
&nbsp; &nbsp; &nbsp; &nbsp; &nbsp; &nbsp; &nbsp; &nbsp; &nbsp; &nbsp; &nbsp; &nbsp; arm.xacro  
&nbsp; &nbsp; &nbsp; &nbsp; &nbsp; &nbsp; &nbsp; &nbsp; &nbsp; &nbsp; &nbsp; &nbsp; body.xacro  
&nbsp; &nbsp; &nbsp; &nbsp; &nbsp; &nbsp; &nbsp; &nbsp; &nbsp; &nbsp; &nbsp; &nbsp; sensors.xacro  
&nbsp; &nbsp; &nbsp; &nbsp; &nbsp; &nbsp; &nbsp; &nbsp; &nbsp; &nbsp; &nbsp; &nbsp; ...  
&nbsp; &nbsp; &nbsp; &nbsp; &nbsp; &nbsp; &nbsp; &nbsp; [hardware](#hardware-interfaces)  
&nbsp; &nbsp; &nbsp; &nbsp; &nbsp; &nbsp; &nbsp; &nbsp; &nbsp; &nbsp; &nbsp; &nbsp; include  
&nbsp; &nbsp; &nbsp; &nbsp; &nbsp; &nbsp; &nbsp; &nbsp; &nbsp; &nbsp; &nbsp; &nbsp; &nbsp; &nbsp; &nbsp; &nbsp; Package_name  
&nbsp; &nbsp; &nbsp; &nbsp; &nbsp; &nbsp; &nbsp; &nbsp; &nbsp; &nbsp; &nbsp; &nbsp; &nbsp; &nbsp; &nbsp; &nbsp; &nbsp; &nbsp; &nbsp; &nbsp; interface1.hpp  
&nbsp; &nbsp; &nbsp; &nbsp; &nbsp; &nbsp; &nbsp; &nbsp; &nbsp; &nbsp; &nbsp; &nbsp; &nbsp; &nbsp; &nbsp; &nbsp; &nbsp; &nbsp; &nbsp; &nbsp; interface2.hpp  
&nbsp; &nbsp; &nbsp; &nbsp; &nbsp; &nbsp; &nbsp; &nbsp; &nbsp; &nbsp; &nbsp; &nbsp; &nbsp; &nbsp; &nbsp; &nbsp; &nbsp; &nbsp; &nbsp; &nbsp; utility.hpp  
&nbsp; &nbsp; &nbsp; &nbsp; &nbsp; &nbsp; &nbsp; &nbsp; &nbsp; &nbsp; &nbsp; &nbsp; interface1.cpp  
&nbsp; &nbsp; &nbsp; &nbsp; &nbsp; &nbsp; &nbsp; &nbsp; &nbsp; &nbsp; &nbsp; &nbsp; interface2.cpp  
&nbsp; &nbsp; &nbsp; &nbsp; &nbsp; &nbsp; &nbsp; &nbsp; CMakeLists.txt  
&nbsp; &nbsp; &nbsp; &nbsp; &nbsp; &nbsp; &nbsp; &nbsp; package.xml  
&nbsp; &nbsp; &nbsp; &nbsp; &nbsp; &nbsp; &nbsp; &nbsp; [ros2_control.xml](#ros2_controlxml)  

<!--TODO
	Ordnerstruktur verfollständigen
-->

<!-- ###############################################################################-->
### URDF  
Das `.urdf` File enthält Informationen über alle Bauteile und Gelenke des Roboters. Ein `.urdf` File kann als grobe Abstraction manuell erstellt, oder aus einem CAD Modell exportiert werden.  
Um die Grundlagen von URDF zu verstehen, ist es ratsam, zunächst manuell ein einfachens `.urdf` File zu schreiben. Dabei helfen diese Tutorials:

[ROS2 URDF Tutorial](https://docs.ros.org/en/humble/Tutorials/Intermediate/URDF/URDF-Main.html)  
[Articulated Robotics Tutorial mit Videos](https://articulatedrobotics.xyz/tutorials/ready-for-ros/urdf/)

Ein `.urdf`File kann auch ohne eine fertige Steuerung inspiziert werden.
Falls das `.urdf` File mit `xacro` erstellt wurde, muss es erst mit

	xacro file_name.urdf.xacro > file_name.urdf

zu einem normalen `.urdf` File kompiliert werden. Danach 2 Terminals öffnen.

	1. ros2 run robot_state_publisher robot_state_publisher file_name.urdf
	2. ros2 run joint_state_publisher_gui joint_state_publisher_gui

`1.` publisht die Position und Lage des Robots, `2.` published das `/tf` Topic und ermöglicht, die Gelenke des Roboters durch Schieber zu bewegen.  

&nbsp;  
**URDF aus CAD**  

Um ein `.urdf` File **aus einem CAD Modell zu extrahieren** z.B. für SolidWorks [hier](https://github.com/ros/solidworks_urdf_exporter) das Plugin installieren und [diesem](https://wiki.ros.org/sw_urdf_exporter/Tutorials/Export%20an%20Assembly) Tutorial folgen. Nach dem Export die URDF mit einem online URDF-Viewer-Tool überprüfen (z.B. [diesem](https://viewer.robotsfan.com/) hier). Dabei auf sinnvolle Rotationsachsen und -limits achten.  

Wenn die exportierten Dateien nach der Überprüfung zufriedenstellend sind, die Ordner `meshes` und `urdf` aus der exportierten Datei in den Ordner `description` kopieren. Anschließend in der `.urdf` Datei bei allen `links` den Dateipfad für die meshes anpassen.

	<mesh filename="package://PACKAGENAME/description/meshes/DATEINAME.STL" />

Hierbei hilft es, den Abschnitt `"package://PACKAGENAME` zu markieren und alle Instanzen davon zu bearbeiten (in VS Code standardmäßig mit `strg`+`F2`).  

Bei Robotern mit vielen unabhängig beweglichen Teilen ist es sinnvoll, die URDF nach Bewegungsgruppen aufzuteilen, um die Übersicht zu behalten. Dann muss auch nicht immer die ganze URDF neu exportiert werden, wenn in der CAD Konstruktion eine Baugruppe überarbeitet wird.

<!-- ###############################################################################-->
### SRDF

<!-- TODO -->

<!-- ###############################################################################-->
### ros2_control.xacro

In dieser Datei werden alle ROS2 Hardware Interfaces aufgezählt, welche Gelenke ihnen zugeordnet sind und welche state- und command-interfaces sie claimen.  
Zusätzlich können hier Parameter hinterlegt werden, die von den Interfaces beim Start ausgelesen werden. Nach Änderungen in dieser Datei muss nicht neu gebuildet werden.  

**Beispieldatei:**

    <?xml version="1.0"?>
    <robot xmlns:xacro="http://www.ros.org/wiki/xacro" >

        <ros2_control name="Group1Name" type="system" rw_rate="50">
            <hardware>
                <plugin>robot_interface1/RobotInterface1</plugin>
                <param name="param1">value1</param>
                <param name="param2">value2</param>
            </hardware>

            <joint name="robot_joint1">
                <command_interface name="position"/>
                <command_interface name="effort"/>
                <state_interface name="position"/>
                <state_interface name="velocity"/>
                <state_interface name="effort"/>
                <state_interface name="temp"/>
            </joint>

            <joint name="robot_joint2">
                <command_interface name="position"/>
                <command_interface name="effort"/>
                <state_interface name="position"/>
                <state_interface name="velocity"/>
                <state_interface name="effort"/>
                <state_interface name="temp"/>
            </joint>
        </ros2_control>

        <ros2_control name="Group2Name" type="system" rw_rate="50">
            <hardware>
                <plugin>robot_interface2/RobotInterface2</plugin>
                <param name="param1">value3</param>
                <param name="param2">value4</param>
            </hardware>

            <joint name="robot_joint3">
                <command_interface name="position"/>
                <command_interface name="effort"/>
                <state_interface name="position"/>
                <state_interface name="velocity"/>
                <state_interface name="effort"/>
                <state_interface name="temp"/>
            </joint>

            <joint name="robot_joint4">
                <command_interface name="position"/>
                <command_interface name="effort"/>
                <state_interface name="position"/>
                <state_interface name="velocity"/>
                <state_interface name="effort"/>
                <state_interface name="temp"/>
            </joint>
        </ros2_control>
    </robot>

Der Header 

    <?xml version="1.0"?>  
    <robot xmlns:xacro="http://www.ros.org/wiki/xacro" > 
    
ist notwendig um `xacro` zu verwenden.

`<ros2_control>` zeigt dem Programm an, dass hier die Hardware Interfaces aufgelistet werden.  
Das Argumente `name="GroupName"` beschreibt, welchen Teil des Roboters die Hardware Interfaces steuern, ist aber nur inerhalb dieser Datei relevant. Falls es z.B. ein Interface für die Räder und eines für den Arm gibt, braucht man zwei ros2_control Gruppen.  
`type="system"` zeigt an, dass es sich um ein System aus Roboterteilen handelt. Andere Kategorien sind für uns vorerst irrelevant.  
`rw_rate="50"` setzt die **read-write-Rate** auf 50 Hz.  

Mit dem Wraper `<hardware>` wird die Beschreibung des Hardware Interfaces für diese Gruppe gestartet. `<plugin>` beschreibt, welches Hardware interface verwendet werden soll. Der name muss mit dem in der `ros2_control.xml` Datei übereinstimmen.  
`<param>` bestimmt die Namen der Parameter, an Stelle von `value1` kommt der Wert des Parameters. Dies kann eine Zahl oder Text sein.  

Nach dem `<hardware>` Abschnitt werden die Gelenke des Roboters aufgelistet, die das Interface steuern kann. Jedes Gelenk startet mit `<joint name="">` der Name des Gelenks muss mit dem in der URDF übereinstimmen. Nach dem Namen des Gelenks wird aufgezählt, welche **command_interfaces** und welche **state_interfaces** das Gelenk hat. **command_interfaces** sind die Befehle, die an den Motor geschickt werden können. **state_interfaces** sind Informationen, die der Motor zurück schickt.  

**Alle Abschnitte die mit `<tagXY>` begonnen wurden, müssen am ende mit `</tagXY>` geschlossen werden.**

&nbsp;  
<!-- ###############################################################################-->
### Hardware Interfaces

Im Ordner `hardware` werden alle Hardware-Interfaces angelegt. Diese sind für die Kommunikation zwischen den Controllern und den Motoren zuständig. Hier werden Umrechnungsfaktoren für Getriebe, Serielle Verbindungen und ähnliches hinterlegt. Generell muss für jede Bewegungsgruppe ein eigenes Hardware-Interface verwendet werden, selbst, wenn beide Gruppen die gleichen Motoren und Controller verwenden, sollte diese Regel beibehalten werden, um interne Konflikte zu vermeiden. Die Lotti2 Interfaces sind so umfangreich, wie möglich kommentiert, um als Vorlage dienen zu können.  
Im Ordner `include` werden die Header-Files der Interfaces angelegt. Sie benennen die Art des Interfaces und etablieren Variablen, die durch die ganze Klasse verwendung finden.

&nbsp;  
<!-- ###############################################################################-->
### ros2_control.xml

Hier werden alle in diesem Package erstellten Hardware Interfaces aufgelistet, damit der ROS2 Controller Manager erkennt, dass er sie exportieren und damit "zur Verfügung stellen" muss.

**Beispiel**

    <library path="lotti2_control">
        <!-- list all hardware interfaces that are specified in this package-->

        <class name="lotti2_flipper_interface/FlipperInterface"
          type="lotti2_flipper_interface::FlipperInterface"
          base_class_type="hardware_interface::SystemInterface">
            <description>
                Interface to drive Lotti's flippers
            </description>
        </class>

        <class name="lotti2_drive_interface/DriveInterface"
          type="lotti2_drive_interface::DriveInterface"
          base_class_type="hardware_interface::SystemInterface">
            <description>
                Interface to drive Lotti's tracks
            </description>
        </class>
  
    </library>

&nbsp;  
<!-- ###############################################################################-->
### controllers.yaml

Die controllers.yaml speichert welche Controller im Roboter zum Einsatz kommen und deren Einstellungen und Parameter. Die Grundstruktur sieht immer gleich aus:

	controller_manager:
	  ros__parameters:
	    update_rate: 50 #Hz

	    joint_state_broadcaster:
	      type: joint_state_broadcaster/JointStateBroadcaster
	
	    Bewegungsgruppe1_controller:
	      type: joint_trajectory_controller/JointTrajectoryController

	    Bewegungsgruppe2_controller:
	      type: lotti2_flipper_controller/FlipperController

	Bewegungsgruppe1_controller:
	  ros__parameters:
	    joints:
	    - joint_name_1
	    - joint_name_2
	    - joint_name_3
	    command_interfaces:
	    - position
	    - effort
	    state_interfaces:
	    - position
	    - effort
	    - velocity
	    - temp

	    parameter1: 50
	    parameter2: 2.0

	Bewegungsgruppe2_controller:
	  ros__parameters:
		joints:
		- joint_name_1
		- joint_name_2
		command_interfaces:
	    - velocity
	    state_interfaces:
	    - position
	    - effort
	    - velocity
	    - temp

	    parameter1: 50
	    parameter2: 2.0

Der Abschnitt

	controller_manager:
	  ros__parameters:
	    update_rate: 50 #Hz

	    joint_state_broadcaster:
	      type: joint_state_broadcaster/JointStateBroadcaster

ist in jedem controller.yaml file gleich. Die default-update-Rate für alle Controller wird benannt und der joint_state_broadcaster wird iniziiert.  

Danach folgen alle Controller, die beim Start des Roboters geladen werden sollen. Sie werden beim Namen genannt (Dieser dient allein der eindeutigen Identifizierung) und ihr Typ wird definiert. Der Typ muss mit einem existierenden Controllertyp übereinstimmen. Auch selbstgeschriebene Controller können hier genannt werden. (siehe z.B. lotti2_flipper_controller)

Danach werden unter den Controllernamen die ihnen zugeordneten Gelenke (Joints) sowie die Command- und State-Interfaces und ihre Parameter aufgelistet.  

Die Formatierung dieser Datei ist entscheidend und muss der Vorlage entsprechen. Beim Builden werden Formatierungsfehler und falsche Bezeichnungen in der Regel nicht besonders gut benannt. Auch beim Start des Packages wird oft nur der Hinweis 'Error in controlers.yaml' oder etwas vergleichbares eingeblendet und der Prozess schlägt fehl.

&nbsp;  
<!-- ###############################################################################-->
### launch-File erstellen

<!-- TODO -->

&nbsp;  
<!-- ###############################################################################-->
### CMakeLists.txt anpassen

<!-- TODO -->

<!-- ##################################################################################
#######################################################################################
####################################################################################-->
&nbsp;  
&nbsp;  
&nbsp;  
&nbsp;  
## Moveit2 Integration

<!--TODO
	Packagename muss "Robotername_moveit_config" sein
	setupassist starten
	package builden
	moveit_config.yaml in ros2_control Package einbinden
	service call für servo_node 
	>

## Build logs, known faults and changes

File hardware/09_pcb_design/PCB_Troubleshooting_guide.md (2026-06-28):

# PCB Troubleshooting Guide
What to do if the PCB stops delivering Power

## Step 1 - If it burns -> it's bad.
Disconnect everything and press the emergency Stop.
Look if anything is really burned or fried, or where the smoke came from.

### Very bad situation -> requires further troubleshooting.
Best to just abandon the PCB and use the backup one. 
See -> what is missing from the Backup.

## Step 2 - If it's just not properly providing power
Measure if the Batteries provide the Proper voltage.
If they do then check and replace the fuse.

You can check if the Relais click if you turn them on.

You can measure if you have a short between VCC and GND. (Beware of the proper direction of the Multimeter).

Check all of the Diodes with the Multimeter. There are 2 THT Diodes on the front and 2-4 SMD Diodes on the Back.

Check if the FETs (Q2 and Q3) are shorted somewhere. If they are you should desolder them and short Pin 3 and 2 (see schematic and Board file).

Alternativly you can use the backup board and solder the missing components (U2, U7, IC1, IC4) from the old board to the new. then it should work. Make sure the Extra Cables are still there. Maybe add the missing fusebox (See backup Components).

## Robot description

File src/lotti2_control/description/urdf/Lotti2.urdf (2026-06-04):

<?xml version="1.0" ?>
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
<robot name="Lotti2">
  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
  <joint name="arm_base_joint" type="fixed">
    <origin rpy="0 0 0" xyz="0.24999999999999997 0 0.15"/>
    <parent link="body_link"/>
    <child link="arm_base_link"/>
  </joint>
  <link name="arm_base_link">
    <inertial>
      <origin rpy="0 0 0" xyz="-0.0002249 -1.7664E-07 0.028417"/>
      <mass value="0.095547"/>
      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
    </inertial>
    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
  </link>
  <link name="arm1_link">
    <inertial>
      <origin rpy="0 0 0" xyz="0.00015473 0.0066378 0.039559"/>
      <mass value="0.13887"/>
      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
    </inertial>
    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
  </link>
  <joint name="arm1_joint" type="revolute">
    <origin rpy="0 0 0" xyz="0 0 0.048"/>
    <parent link="arm_base_link"/>
    <child link="arm1_link"/>
    <axis xyz="0 0 -1"/>
    <limit effort="0" lower="-3.0" upper="3.0" velocity="0"/>
  </joint>
  <link name="arm2_link">
    <inertial>
      <origin rpy="0 0 0" xyz="-0.09 0.009887 -2.6229E-15"/>
      <mass value="0.044594"/>
      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
    </inertial>
    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
  </link>
  <joint name="arm2_joint" type="revolute">
    <origin rpy="0 0 0" xyz="0 0.04285 0.04755"/>
    <parent link="arm1_link"/>
    <child link="arm2_link"/>
    <axis xyz="0 1 0"/>
    <limit effort="0" lower="-0.1" upper="3.2" velocity="0"/>
  </joint>
  <link name="arm3_link">
    <inertial>
      <origin rpy="0 0 0" xyz="0.0037748 -0.022075 0.02755"/>
      <mass value="0.23565"/>
      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
    </inertial>
    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
  </link>
  <joint name="arm3_joint" type="revolute">
    <origin rpy="0 0.0 0" xyz="-0.18 -0.017 0"/>
    <parent link="arm2_link"/>
    <child link="arm3_link"/>
    <axis xyz="0 1 0"/>
    <limit effort="0" lower="-3.5" upper="0.1" velocity="0"/>
  </joint>
  <link name="arm4_link">
    <inertial>
      <origin rpy="0 0 0" xyz="0.13759 -0.0029301 7.5985E-05"/>
      <mass value="0.14345"/>
      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
    </inertial>
    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
  </link>
  <joint name="arm4_joint" type="revolute">
    <origin rpy="0 0 0" xyz="0.04285 -0.02585 0.0551"/>
    <parent link="arm3_link"/>
    <child link="arm4_link"/>
    <axis xyz="1 0 0"/>
    <limit effort="0" lower="-3.5" upper="3.5" velocity="0"/>
  </joint>
  <link name="arm5_link">
    <inertial>
      <origin rpy="0 0 0" xyz="0.063464 0.023999 0.0010452"/>
      <mass value="0.10145"/>
      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
    </inertial>
    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
  </link>
  <joint name="arm5_joint" type="revolute">
    <origin rpy="0 0 0" xyz="0.18185 -0.0325 0"/>
    <parent link="arm4_link"/>
    <child link="arm5_link"/>
    <axis xyz="0 -1 0"/>
    <limit effort="0" lower="-3.5" upper="3.5" velocity="0"/>
  </joint>
  <link name="arm6_link">
    <inertial>
      <origin rpy="0 0 0" xyz="0.012243 -5.2736E-16 0"/>
      <mass value="0.016119"/>
      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
    </inertial>
    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
  </link>
  <joint name="arm6_joint" type="revolute">
    <origin rpy="0 0 0" xyz="0.096443 0.0316 0"/>
    <parent link="arm5_link"/>
    <child link="arm6_link"/>
    <axis xyz="-1 0 0"/>
    <limit effort="0" lower="-3.5" upper="3.5" velocity="0"/>
  </joint>
  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
  <link name="body_link">
    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
    <innertial/>
    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
  </link>
  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
  <joint name="left_chain_joint" type="continuous">
    <origin rpy="0 0 0" xyz="0 0.09000000000000001 0.11"/>
    <parent link="body_link"/>
    <child link="left_chain_link"/>
    <axis xyz="0 -1 0"/>
  </joint>
  <link name="left_chain_link">
    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
    <inertial>
      <origin rpy="0 0 0" xyz="0 0 0"/>
      <mass value="1"/>
      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
    </inertial>
  </link>
  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
  <joint name="right_chain_joint" type="continuous">
    <origin rpy="0 0 0" xyz="0 -0.09000000000000001 0.11"/>
    <parent link="body_link"/>
    <child link="right_chain_link"/>
    <axis xyz="0 1 0"/>
  </joint>
  <link name="right_chain_link">
    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
    <inertial>
      <origin rpy="0 0 0" xyz="0 0 0"/>
      <mass value="1"/>
      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
    </inertial>
  </link>
  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
  <joint name="flipper_fr_joint" type="continuous">
    <origin rpy="0 3.141592653589793 0" xyz="0.24999999999999997 -0.19 0.1"/>
    <parent link="body_link"/>
    <child link="flipper_fr_link"/>
    <axis xyz="0 1 0"/>
  </joint>
  <link name="flipper_fr_link">
    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
    <inertial>
      <origin rpy="0 0 0" xyz="-0.1 0 0"/>
      <mass value="3.0"/>
      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
    </inertial>
  </link>
  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
  <joint name="flipper_fl_joint" type="continuous">
    <origin rpy="0 3.141592653589793 0" xyz="0.24999999999999997 0.19 0.1"/>
    <parent link="body_link"/>
    <child link="flipper_fl_link"/>
    <axis xyz="0 1 0"/>
  </joint>
  <link name="flipper_fl_link">
    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
    <inertial>
      <origin rpy="0 0 0" xyz="-0.1 0 0"/>
      <mass value="3.0"/>
      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
    </inertial>
  </link>
  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
  <joint name="flipper_rr_joint" type="continuous">
    <origin rpy="0 0 0" xyz="-0.24999999999999997 -0.19 0.1"/>
    <parent link="body_link"/>
    <child link="flipper_rr_link"/>
    <axis xyz="0 -1 0"/>
  </joint>
  <link name="flipper_rr_link">
    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
    <inertial>
      <origin rpy="0 0 0" xyz="-0.1 0 0"/>
      <mass value="3.0"/>
      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
    </inertial>
  </link>
  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
  <joint name="flipper_rl_joint" type="continuous">
    <origin rpy="0 0 0" xyz="-0.24999999999999997 0.19 0.1"/>
    <parent link="body_link"/>
    <child link="flipper_rl_link"/>
    <axis xyz="0 -1 0"/>
  </joint>
  <link name="flipper_rl_link">
    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
    <inertial>
      <origin rpy="0 0 0" xyz="-0.1 0 0"/>
      <mass value="3.0"/>
      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
    </inertial>
  </link>
  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
  <ros2_control name="Lotti2Flipper" rw_rate="50" type="system">
    <hardware>
      <plugin>lotti2_flipper_interface/FlipperInterface</plugin>
      <param name="device">/dev/serial/by-id/usb-FTDI_USB__-__Serial_Converter_FTA2HIEQ-if00-port0</param>
      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
      <param name="use_hardware">0</param>
    </hardware>
    <joint name="flipper_fr_joint">
      <command_interface name="position"/>
      <state_interface name="position"/>
      <state_interface name="velocity"/>
      <state_interface name="effort"/>
      <state_interface name="temp"/>
    </joint>
    <joint name="flipper_fl_joint">
      <command_interface name="position"/>
      <state_interface name="position"/>
      <state_interface name="velocity"/>
      <state_interface name="effort"/>
      <state_interface name="temp"/>
    </joint>
    <joint name="flipper_rr_joint">
      <command_interface name="position"/>
      <state_interface name="position"/>
      <state_interface name="velocity"/>
      <state_interface name="effort"/>
      <state_interface name="temp"/>
    </joint>
    <joint name="flipper_rl_joint">
      <command_interface name="position"/>
      <state_interface name="position"/>
      <state_interface name="velocity"/>
      <state_interface name="effort"/>
      <state_interface name="temp"/>
    </joint>
  </ros2_control>
  <ros2_control name="Lotti2Chains" type="system">
    <hardware>
      <plugin>lotti2_drive_interface/DriveInterface</plugin>
      <param name="device">/dev/serial/by-id/usb-1a86_USB_Serial-if00-port0</param>
      <param name="e_conversion">21</param>
      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
      <param name="gear_ratio">9</param>
      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
      <param name="Kt">0.198</param>
      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
      <param name="use_hardware">0</param>
    </hardware>
    <joint name="left_chain_joint">
      <command_interface name="velocity"/>
      <state_interface name="position"/>
      <state_interface name="velocity"/>
      <state_interface name="effort"/>
      <state_interface name="temp"/>
    </joint>
    <joint name="right_chain_joint">
      <command_interface name="velocity"/>
      <state_interface name="position"/>
      <state_interface name="velocity"/>
      <state_interface name="effort"/>
      <state_interface name="temp"/>
    </joint>
  </ros2_control>
  <ros2_control name="Lotti2Arm" rw_rate="50" type="system">
    <hardware>
      <plugin>lotti2_arm_interface/ArmInterface</plugin>
      <param name="device"/>
      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
      <param name="use_synchronization">0</param>
      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
      <param name="gear_ratio">25.0</param>
      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
      <param name="resolution">16384</param>
      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
      <param name="acceleration">100</param>
      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

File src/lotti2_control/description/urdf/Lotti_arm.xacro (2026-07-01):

<?xml version="1.0" encoding="utf-8"?>
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
<robot xmlns:xacro="http://www.ros.org/wiki/xacro" >

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
  <xacro:property name="body_length" value="0.7"/>
  <xacro:property name="body_width" value="0.33"/>
  <xacro:property name="body_height" value="0.15"/>
  <xacro:property name="body_mass" value="25.0"/>


  <joint name="arm_base_joint" type="fixed">
    <origin xyz="${body_length/2 - 0.1} 0 ${body_height}" rpy="0 0 0" />
    <parent link="body_link" />
    <child link="arm_base_link" />
  </joint>

  <link name="arm_base_link">
    <inertial>
      <origin xyz="-0.000224896614335376 -1.76636436838296E-07 0.0284165324113623" rpy="0 0 0" />
      <mass value="0.095546621133873" />
      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
    </inertial>
    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
  </link>

  <link name="arm1_link">
    <inertial>
      <origin xyz="-0.000148896967024248 0.0077665679059083 0.0349624287308134" rpy="0 0 0" />
      <mass value="0.144567896175452" />
      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
    </inertial>
    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
  </link>

  <joint name="arm1_joint" type="revolute">
    <origin xyz="0 0 0.051" rpy="0 0 0" />
    <parent link="arm_base_link" />
    <child link="arm1_link" />
    <axis xyz="0 0 1" />
    <limit lower="-3.2" upper="3.2" effort="0" velocity="8" />
  </joint>

  <link name="arm2_link">
    <inertial>
      <origin xyz="-0.0900000000000001 0.00988701341491088 1.11022302462516E-16" rpy="0 0 0" />
      <mass value="0.0445936683001197" />
      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
    </inertial>
    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
  </link>

  <joint name="arm2_joint" type="revolute">
    <origin xyz="0 0.04285 0.04255" rpy="0 0 0" />
    <parent link="arm1_link" />
    <child link="arm2_link" />
    <axis xyz="0 1 0" />
    <limit lower="-0.1" upper="3.3" effort="0" velocity="8" />
  </joint>

  <link name="arm3_link">
    <inertial>
      <origin xyz="0.0034648183052334 -0.0383852430442727 0.0255502171970031" rpy="0 0 0" />
      <mass value="0.245453937373138" />
      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
    </inertial>
    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
  </link>

  <joint name="arm3_joint" type="revolute">
    <origin xyz="-0.18 0 0" rpy="0 0 0" />
    <parent link="arm2_link" />
    <child link="arm3_link" />
    <axis xyz="0 -1 0" />
    <limit lower="-0.1" upper="3.3" effort="0" velocity="8" />
  </joint>

  <link name="arm4_link">
    <inertial>
      <origin xyz="0.129288922794988 -0.00357560359269317 0.000163536166512185" rpy="0 0 0" />
      <mass value="0.172732716660201" />
      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
    </inertial>
    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
  </link>

  <joint name="arm4_joint" type="revolute">
    <origin xyz="0.04185 -0.04185 0.0511" rpy="0 0 0" />
    <parent link="arm3_link" />
    <child link="arm4_link" />
    <axis xyz="-1 0 0" />
    <limit lower="-3.3" upper="3.3" effort="0" velocity="8" />
  </joint>

  <link name="arm5_link">
    <inertial>
      <origin xyz="0.0572619375972157 0.0117814736268077 0.0431395601131012" rpy="0 0 0" />
      <mass value="0.128456713327902" />
      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
    </inertial>
    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
  </link>

  <joint name="arm5_joint" type="revolute">
    <origin xyz="0.18285 -0.0247 0.0002" rpy="0 0 0" />
    <parent link="arm4_link" />
    <child link="arm5_link" />
    <axis xyz="0 -1 0" />
    <limit lower="-3.3" upper="3.3" effort="0" velocity="8" />
  </joint>

  <link name="arm6_link">
    <inertial>
      <origin xyz="0.0201016161435498 -0.00611223511695827 -0.00143428025220876" rpy="0 0 0" />
      <mass value="0.0876078923434119" />
      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
    </inertial>
    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
  </link>

  <joint name="arm6_joint" type="revolute">
    <origin xyz="0.098 0.0245 0.0545" rpy="0 0 0" />
    <parent link="arm5_link" />
    <child link="arm6_link" />
    <axis xyz="1 0 0" />
    <limit lower="-3.3" upper="3.3" effort="0" velocity="8" />
  </joint>

  <link name="arm7_link">
    <inertial>
      <origin xyz="0.0239205093893826 -0.00145000228983914 0.000403955591261024" rpy="0 0 0" />
      <mass value="0.0194375934693886" />
      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
    </inertial>
    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
  </link>
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

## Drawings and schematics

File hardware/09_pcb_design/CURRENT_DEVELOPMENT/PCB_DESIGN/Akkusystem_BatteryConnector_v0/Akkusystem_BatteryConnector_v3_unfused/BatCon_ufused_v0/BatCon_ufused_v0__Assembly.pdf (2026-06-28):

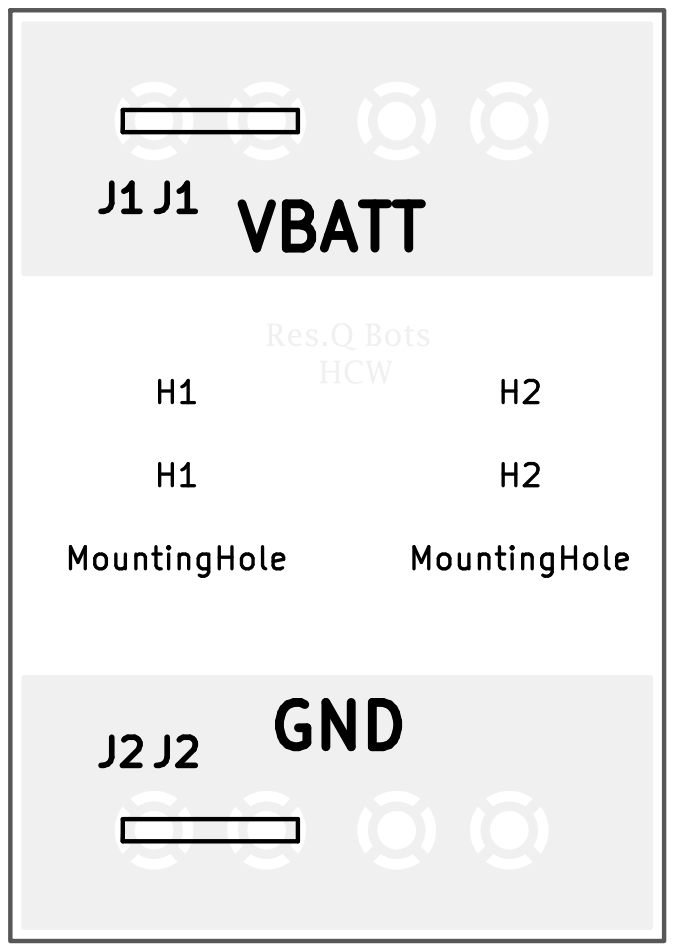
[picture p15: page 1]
VBATT; GND; D Date: KiCad; E.D.A. 9.0.6 Size: A4; Rev:; Id: /1 Title: File: BatCon_ufused_v0.kicad_pcb Sheet: Black; And; White; TOP; Board2Pdf:; Black; TOP -; Page; MountingHole H2 MountingHole H1 J2

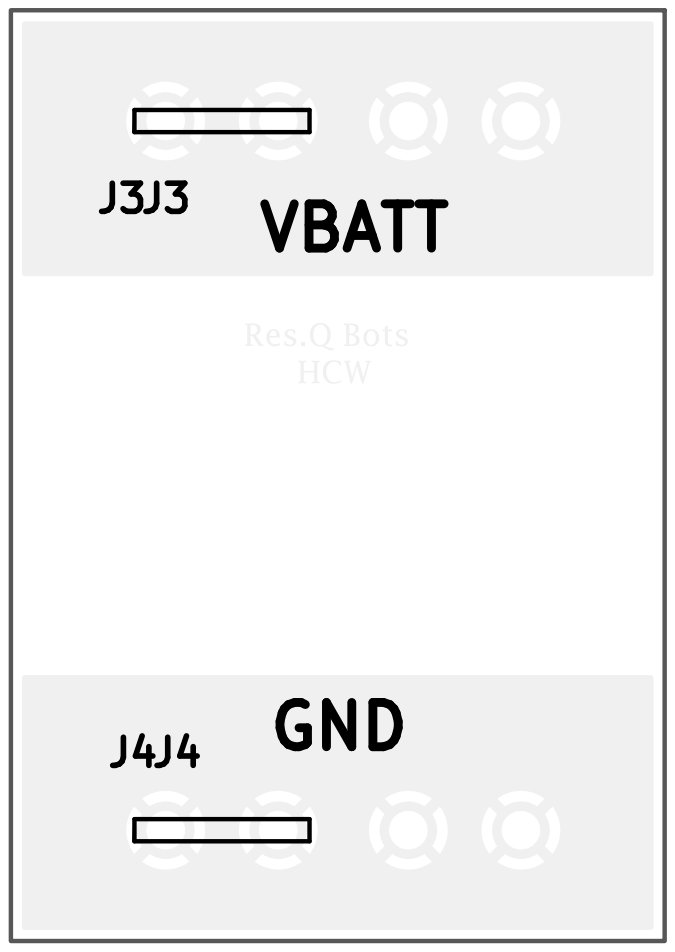
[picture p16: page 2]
VBATT; GND J4; D Date: KiCad; E.D.A. 9.0.6 Size: A4; Rev:; Id: /1 Title: File: BatCon_ufused_v0.kicad_pcb Sheet: Black; And; White; BOT Board2Pdf:; Black; BOT -; Page 2/8

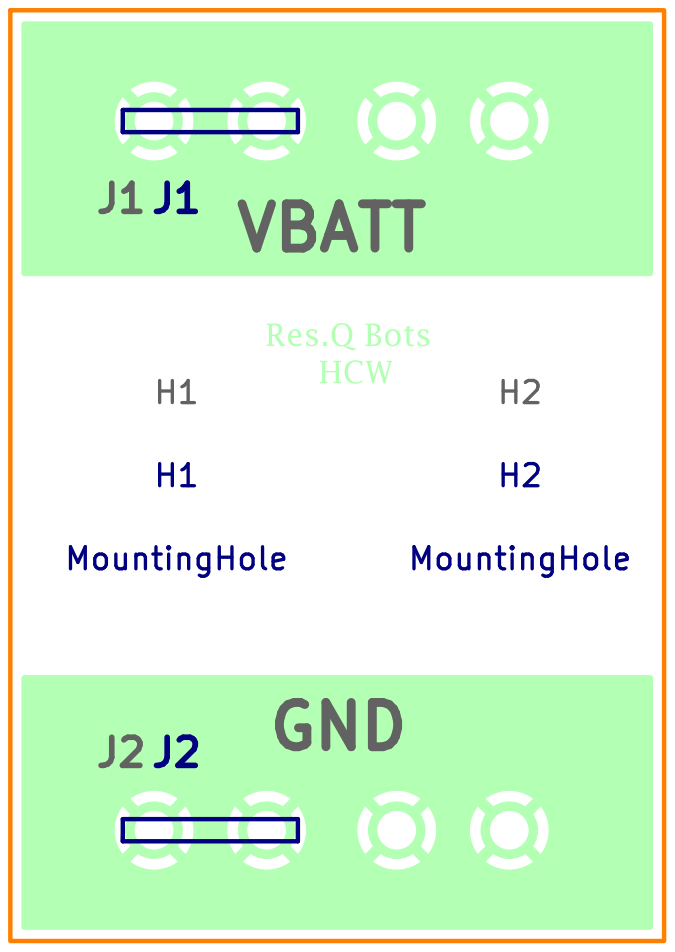
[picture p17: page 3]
VBATT; GND; D Date: KiCad; E.D.A. 9.0.6 Size: A4; Rev:; Id: /1 Title: File: BatCon_ufused_v0.kicad_pcb Sheet: Colored; TOP; Board2Pdf:; Colored; TOP -; Page 3/8; MountingHole H2 MountingHole H1 J2

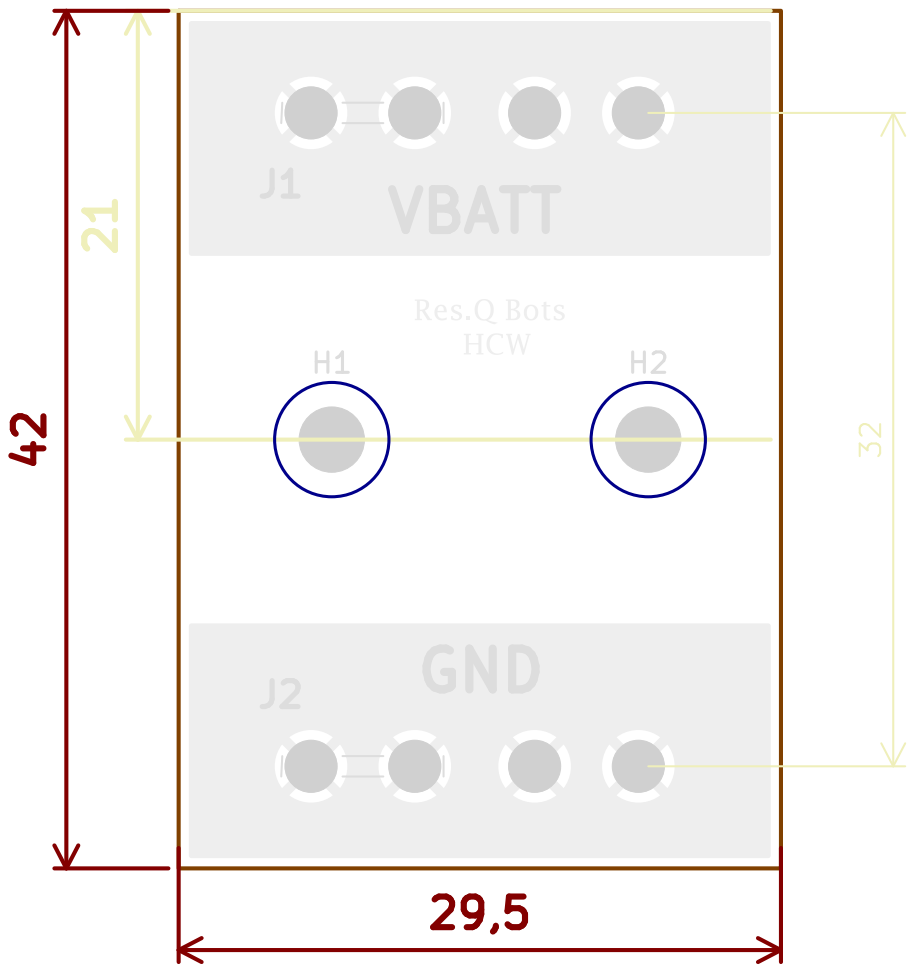
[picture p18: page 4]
VBATT; GND; D Date: KiCad; E.D.A. 9.0.6 Size: A4; Rev:; Id: /1 Title: File: BatCon_ufused_v0.kicad_pcb Sheet: Light Colors; PCB; Fabrication; TOP; Board2Pdf:; Light Colors; TOP -; Page 4/8

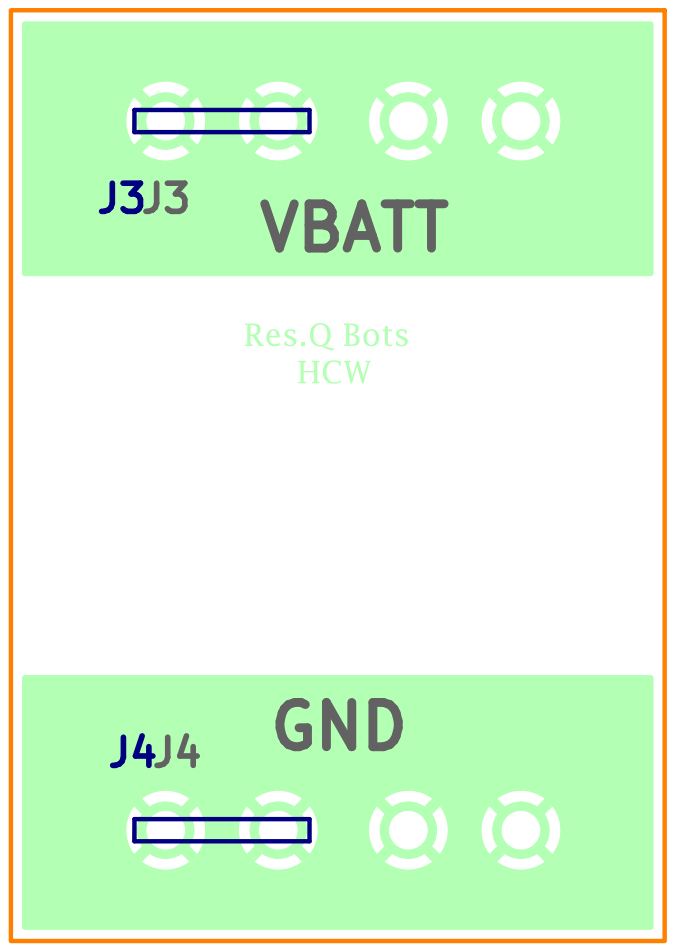
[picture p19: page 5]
VBATT; GND J4; D Date: KiCad; E.D.A. 9.0.6 Size: A4; Rev:; Id: /1 Title: File: BatCon_ufused_v0.kicad_pcb Sheet: Colored; BOT Board2Pdf:; Colored; BOT -; Page 5/8

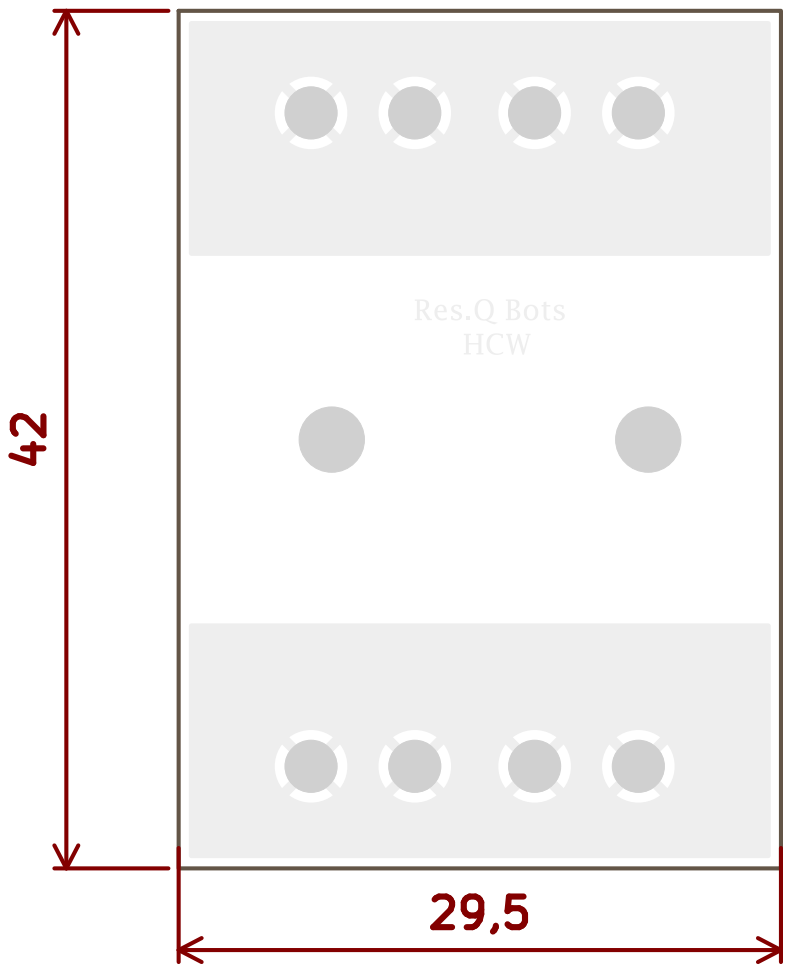
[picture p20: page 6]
D Date: KiCad; E.D.A. 9.0.6 Size: A4; Rev:; Id: /1 Title: File: BatCon_ufused_v0.kicad_pcb Sheet: Light Colors; PCB; Paste; TOP; Board2Pdf:; Light Colors; TOP -; Page 6/8

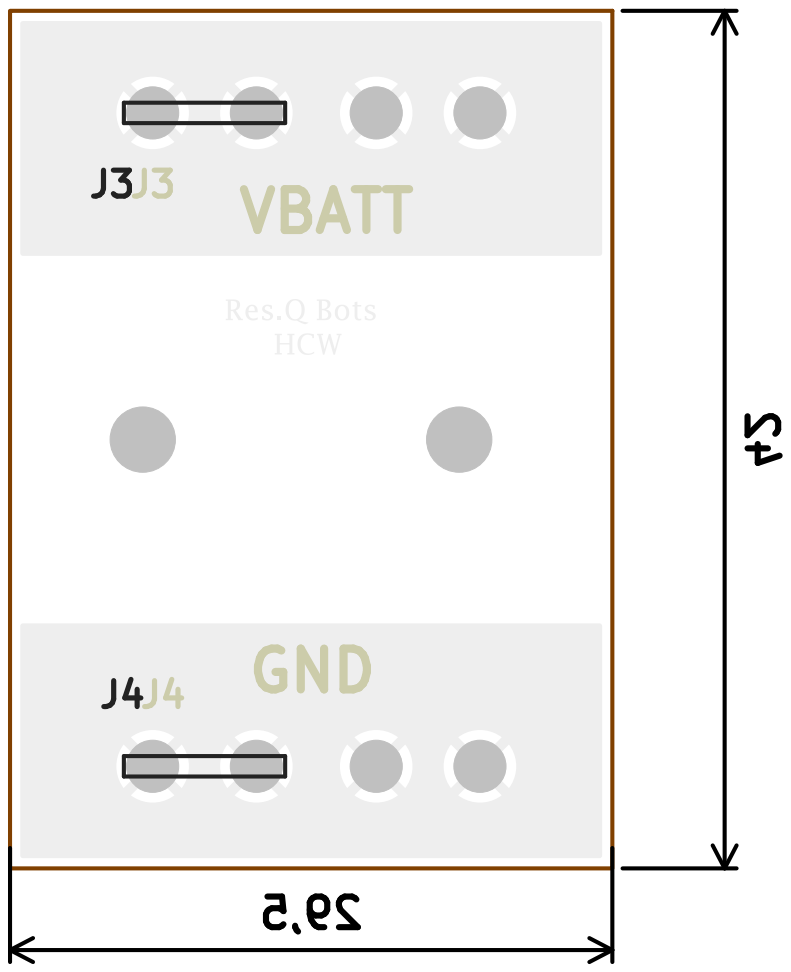
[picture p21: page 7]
VBATT; GND J4; D Date: KiCad; E.D.A. 9.0.6 Size: A4; Rev:; Id: /1 Title: File: BatCon_ufused_v0.kicad_pcb Sheet: Light Colors; Placement; BOT Board2Pdf:; Light Colors; BOT -; Page 7/8

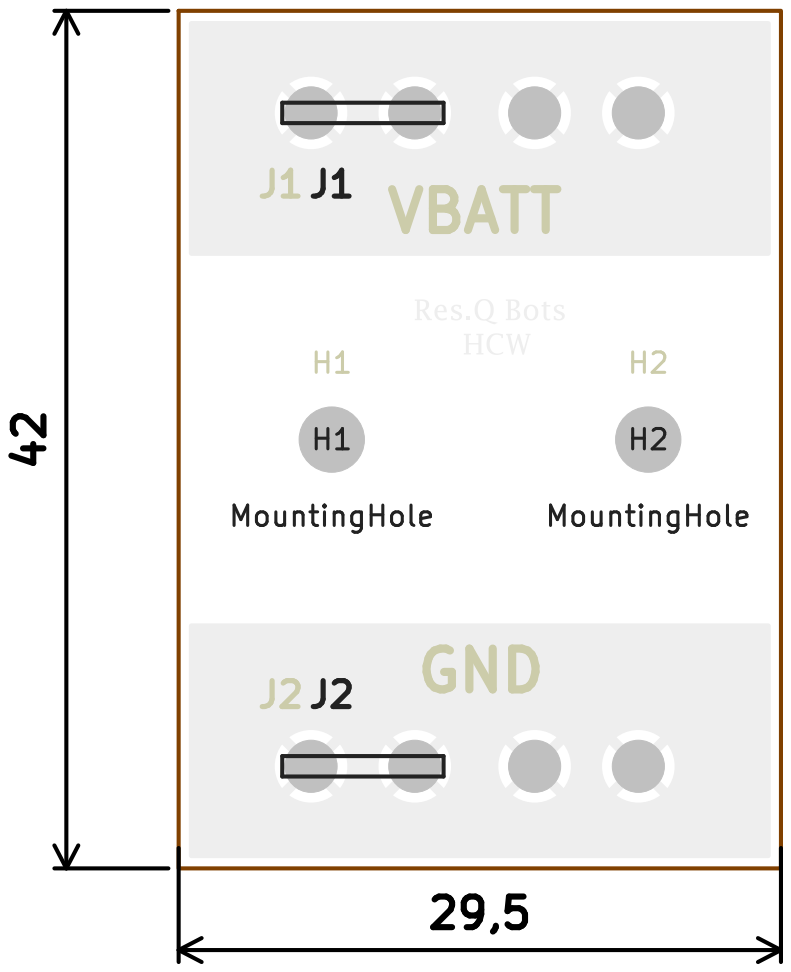
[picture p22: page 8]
VBATT; GND; MountingHole H2 MountingHole H1 J2; D Date: KiCad; E.D.A. 9.0.6 Size: A4; Rev:; Id: /1 Title: File: BatCon_ufused_v0.kicad_pcb Sheet: Light Colors; Placement; TOP; Board2Pdf:; Light Colors; TOP -; Page 8/8

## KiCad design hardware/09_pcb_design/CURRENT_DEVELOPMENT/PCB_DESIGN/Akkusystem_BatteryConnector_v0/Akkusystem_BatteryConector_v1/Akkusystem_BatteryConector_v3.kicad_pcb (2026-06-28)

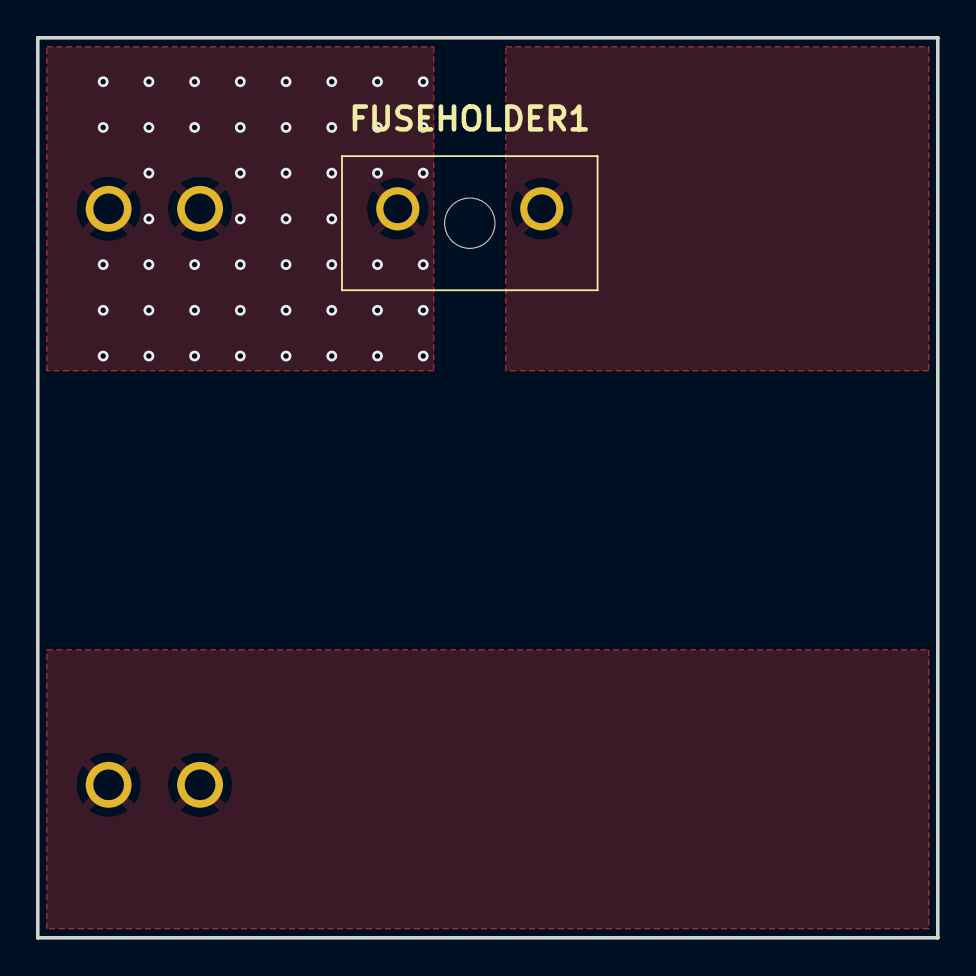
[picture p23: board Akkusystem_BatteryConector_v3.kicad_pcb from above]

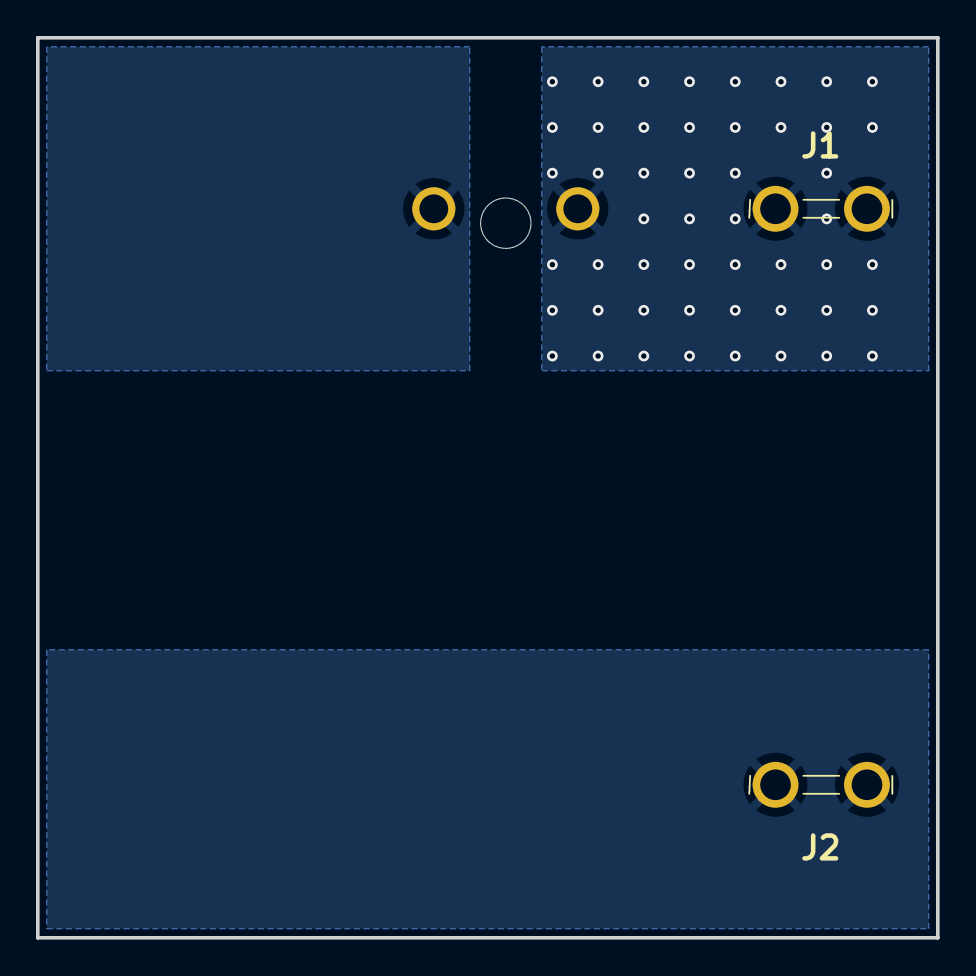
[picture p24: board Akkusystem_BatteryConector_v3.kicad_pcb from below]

Board: 2 copper layers, 50.0 x 50.0 mm, 3 parts (2 on the bottom side), 2 nets, no tracks yet.

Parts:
FUSEHOLDER1: 178.6764.0001; 17867640001
J1, J2: 19705-4201; 197054201

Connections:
GND: J2.1, J2.2
unnamed: FUSEHOLDER1.1, J1.1, J1.2

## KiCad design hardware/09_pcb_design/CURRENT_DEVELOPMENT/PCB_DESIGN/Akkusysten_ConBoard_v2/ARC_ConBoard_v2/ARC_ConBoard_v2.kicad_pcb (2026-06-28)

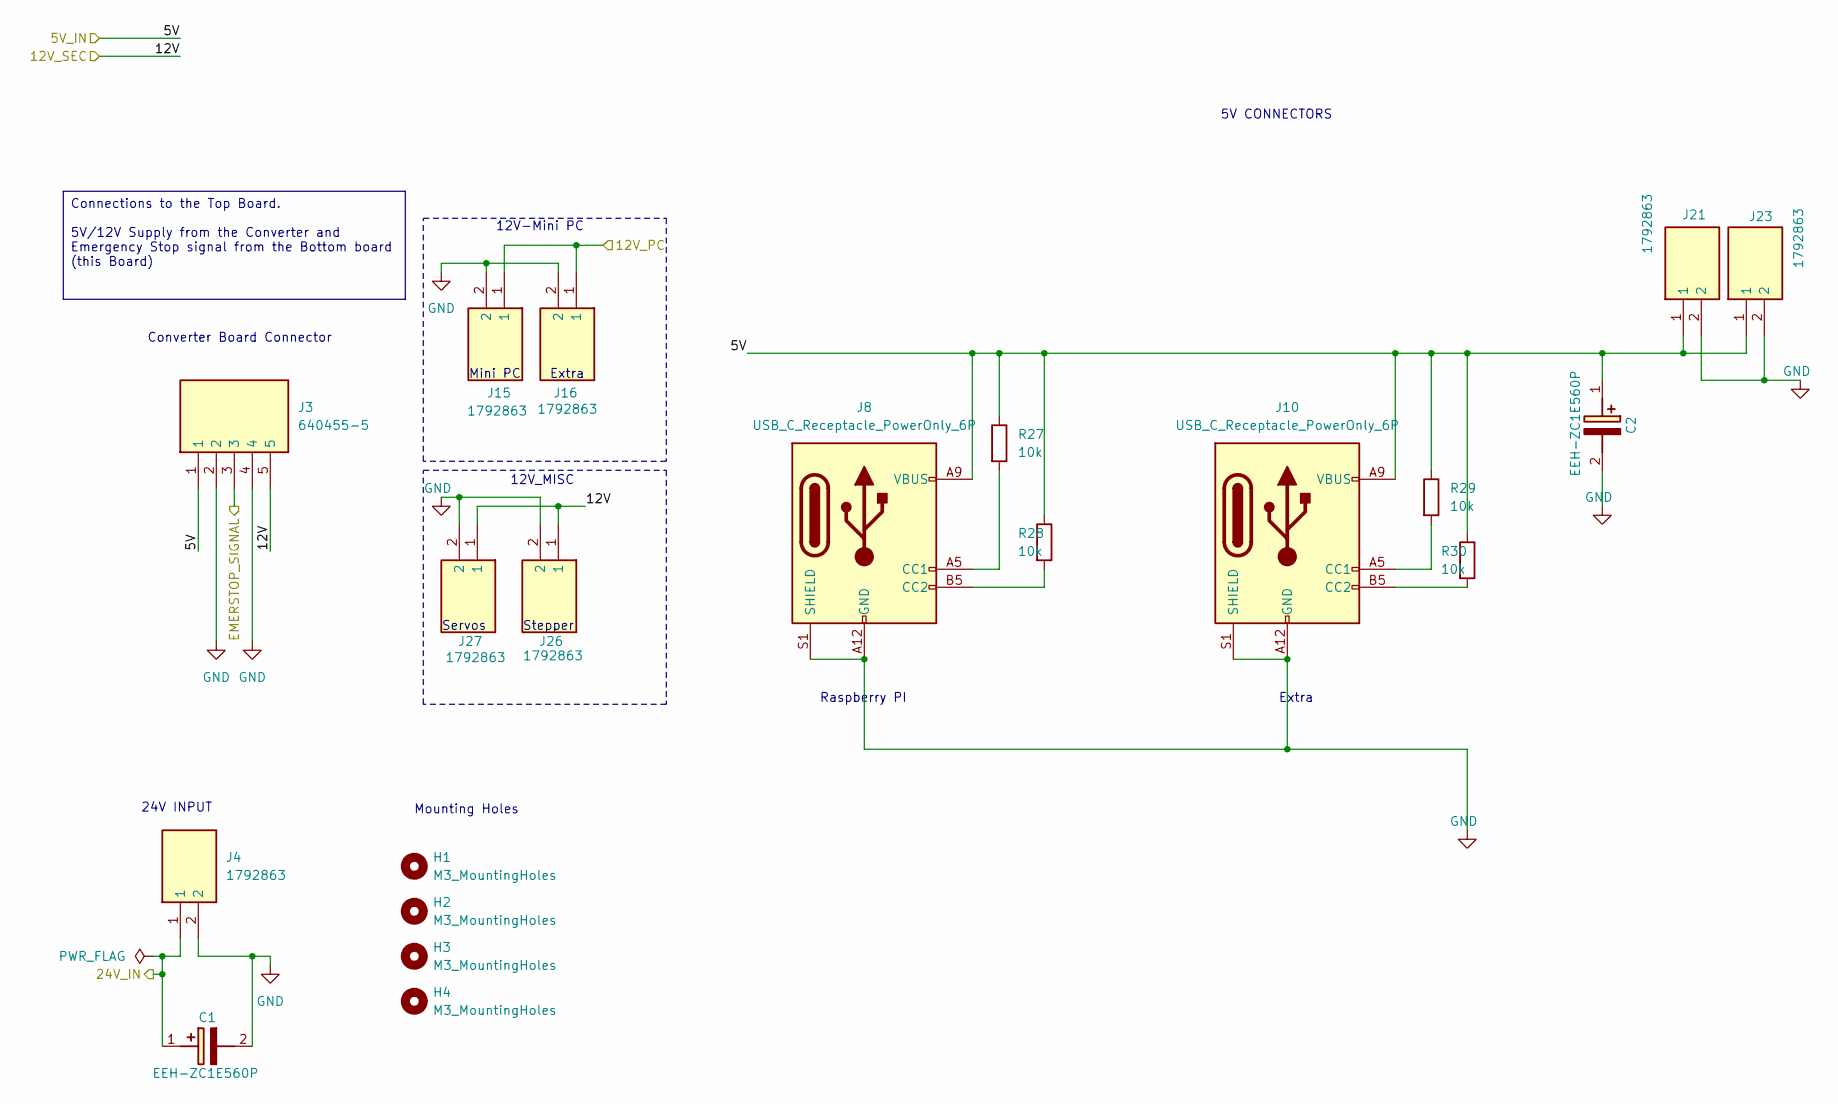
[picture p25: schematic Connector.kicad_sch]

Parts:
C1, C2: EEH-ZC1E560P; EEHZA1E101XP; Mouser Part Number 667-EEH-ZC1E560P
H1, H2, H3, H4: M3_MountingHoles; MountingHole_3.2mm_M3
J3: 640455-5; HDRRA5W88P0X254_1X5_1270X775X610P; Mouser Part Number 571-6404555
J4, J15, J16, J26, J27: 1792863; Mouser Part Number 651-1792863
J8, J10: USB_C_Receptacle_PowerOnly_6P; UJCHGSMT2P6TR
J21, J23: 1792863; PARTREV N/A; Mouser Part Number 651-1792863
R27, R28, R29, R30: 10k; R_1206_3216Metric_Pad1.30x1.75mm_HandSolder

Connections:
/5V: C2.1 (+), J3.1, J8.A9 (VBUS), J8.B9 (VBUS), J10.A9 (VBUS), J10.B9 (VBUS), J21.1, J23.1, R27.1, R28.1, R29.1, R30.1; also elsewhere on the board
/12V: J3.5, J26.1, J27.1; also elsewhere on the board
/12V_PC: J15.1, J16.1; also elsewhere on the board
/24V: C1.1 (+), J4.1; also elsewhere on the board
/EMER: J3.3; also elsewhere on the board
GND: C1.2 (-), C2.2 (-), J3.2, J3.4, J4.2, J8.A12 (GND), J8.B12 (GND), J8.S1 (SHIELD), J10.A12 (GND), J10.B12 (GND), J10.S1 (SHIELD), J15.2, J16.2, J21.2, J23.2, J26.2, J27.2; also elsewhere on the board
unnamed: J8.A5 (CC1), R27.2
unnamed: J8.B5 (CC2), R28.2
unnamed: J10.A5 (CC1), R29.2
unnamed: J10.B5 (CC2), R30.2

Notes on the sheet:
Raspberry PI
12V_MISC
Mounting Holes
Extra
Stepper
Converter Board Connector
Mini PC
12V-Mini PC
24V INPUT
5V CONNECTORS
Servos
Connections to the Top Board. 5V/12V Supply from the Converter and Emergency Stop signal from the Bottom board (this Board)

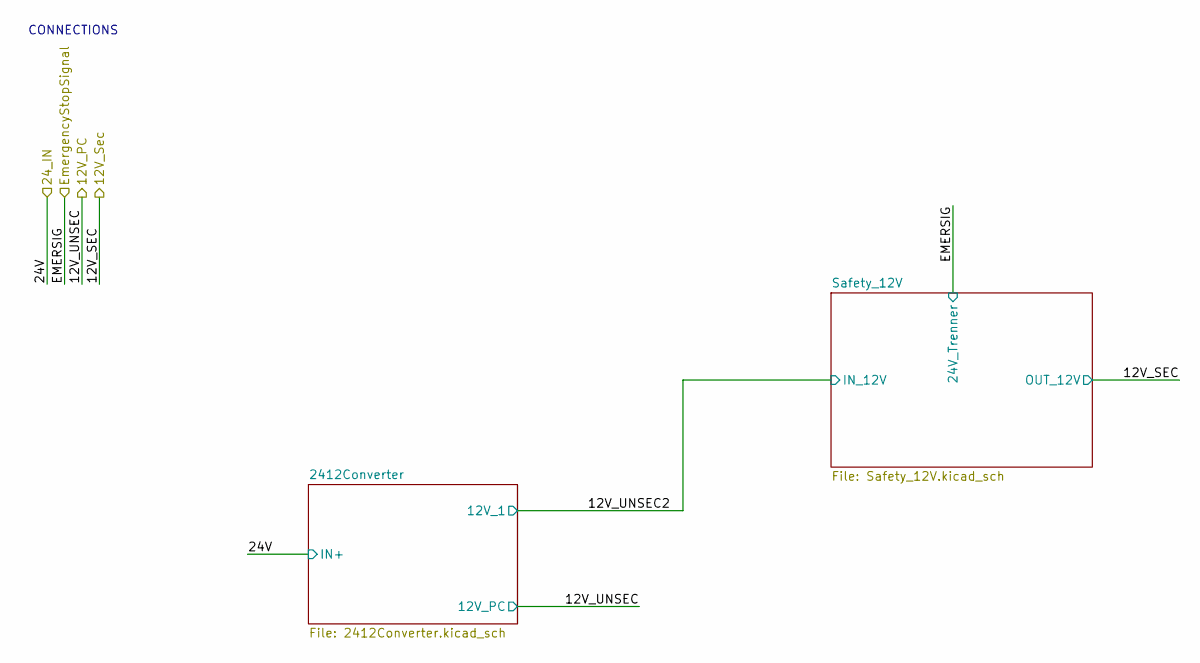
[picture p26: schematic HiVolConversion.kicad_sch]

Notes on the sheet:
CONNECTIONS

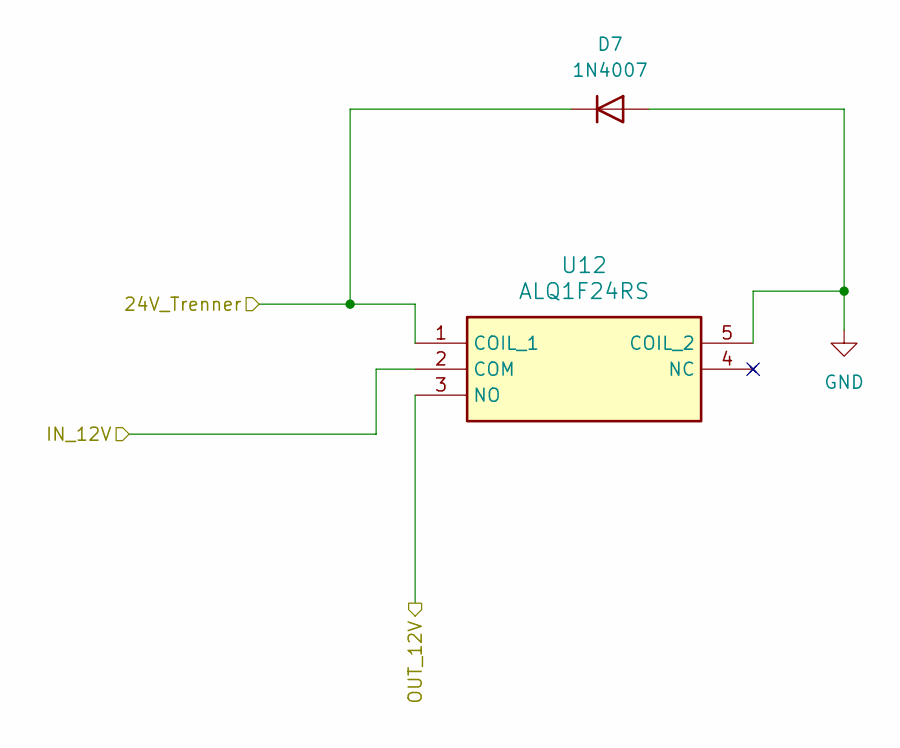
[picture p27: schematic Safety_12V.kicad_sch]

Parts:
D7: 1N4007; D_DO-41_SOD81_P10.16mm_Horizontal
U12: ALQ1F24RS; ALQ112S; Manufacturer_Part_Number ALQ1F24RS

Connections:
/12V: U12.3 (NO); also elsewhere on the board
/EMER: D7.1 (K), U12.1 (COIL_1); also elsewhere on the board
/HiVolConversion/12V_UNSEC2: U12.2 (COM); also elsewhere on the board
GND: D7.2 (A), U12.5 (COIL_2); also elsewhere on the board

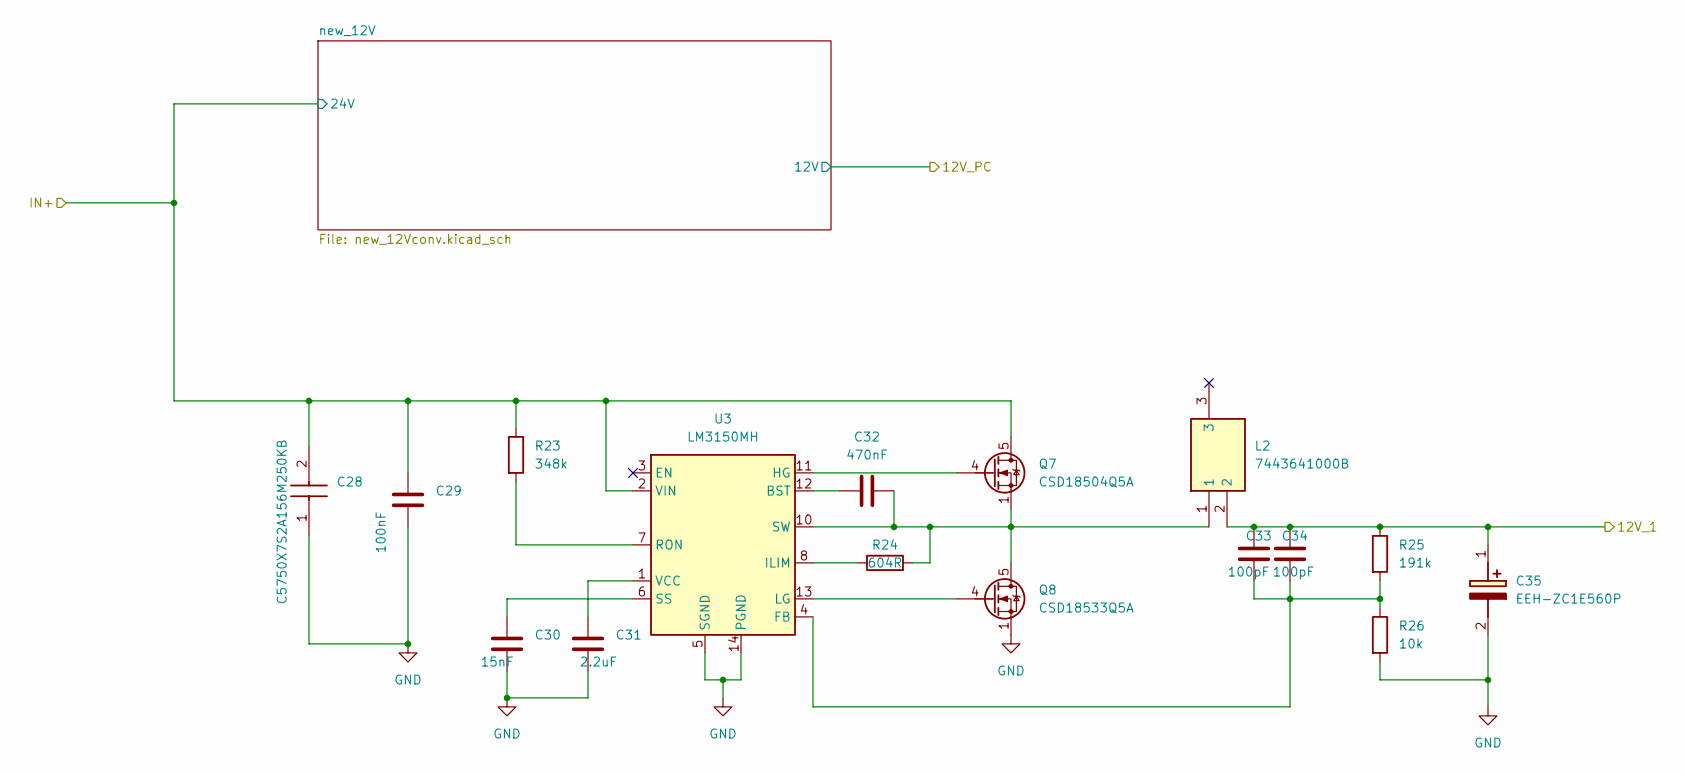
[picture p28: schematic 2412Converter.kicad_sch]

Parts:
C28: C5750X7S2A156M250KB; C5750_Commercial; Mouser Part Number 810-C5750X7S2A156M
C29: 100nF; C_0805_2012Metric_Pad1.18x1.45mm_HandSolder
C30: 15nF; C_0805_2012Metric_Pad1.18x1.45mm_HandSolder
C31: 2.2uF; C_0805_2012Metric_Pad1.18x1.45mm_HandSolder
C32: 470nF; C_1206_3216Metric_Pad1.33x1.80mm_HandSolder
C33, C34: 100pF; C_0805_2012Metric_Pad1.18x1.45mm_HandSolder
C35: EEH-ZC1E560P; EEHZA1E101XP; Mouser Part Number 667-EEH-ZC1E560P
L2: 7443641000B; Mouser Part Number 710-7443641000B
Q7: CSD18504Q5A; TDSON-8-1
Q8: CSD18533Q5A; TDSON-8-1
R23: 348k; R_1206_3216Metric_Pad1.30x1.75mm_HandSolder
R24: 604R; R_1206_3216Metric_Pad1.30x1.75mm_HandSolder
R25: 191k; R_1206_3216Metric_Pad1.30x1.75mm_HandSolder
R26: 10k; R_1206_3216Metric_Pad1.30x1.75mm_HandSolder
U3: LM3150MH; Texas_HTSSOP-14-1EP_4.4x5mm_P0.65mm_EP3.4x5mm_Mask3.155x3.2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

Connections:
/24V: C28.2, C29.1, Q7.5 (D), R23.1, U3.2 (VIN); also elsewhere on the board
/HiVolConversion/12V_UNSEC2: C33.1, C34.1, C35.1 (+), L2.2, R25.1; also elsewhere on the board
GND: C28.1, C29.2, C30.2, C31.2, C35.2 (-), Q8.1 (S), Q8.2 (S), Q8.3 (S), R26.2, U3.5 (SGND), U3.9 (SGND), U3.14 (PGND), U3.15 (SGND); also elsewhere on the board
unnamed: Q7.4 (G), U3.11 (HG)
unnamed: C32.2, L2.1, Q7.1 (S), Q7.2 (S), Q7.3 (S), Q8.5 (D), R24.2, U3.10 (SW)
unnamed: Q8.4 (G), U3.13 (LG)
unnamed: C32.1, U3.12 (BST)
unnamed: C33.2, C34.2, R25.2, R26.1, U3.4 (FB)
unnamed: R24.1, U3.8 (ILIM)
unnamed: R23.2, U3.7 (RON)
unnamed: C30.1, U3.6 (SS)
unnamed: C31.1, U3.1 (VCC)

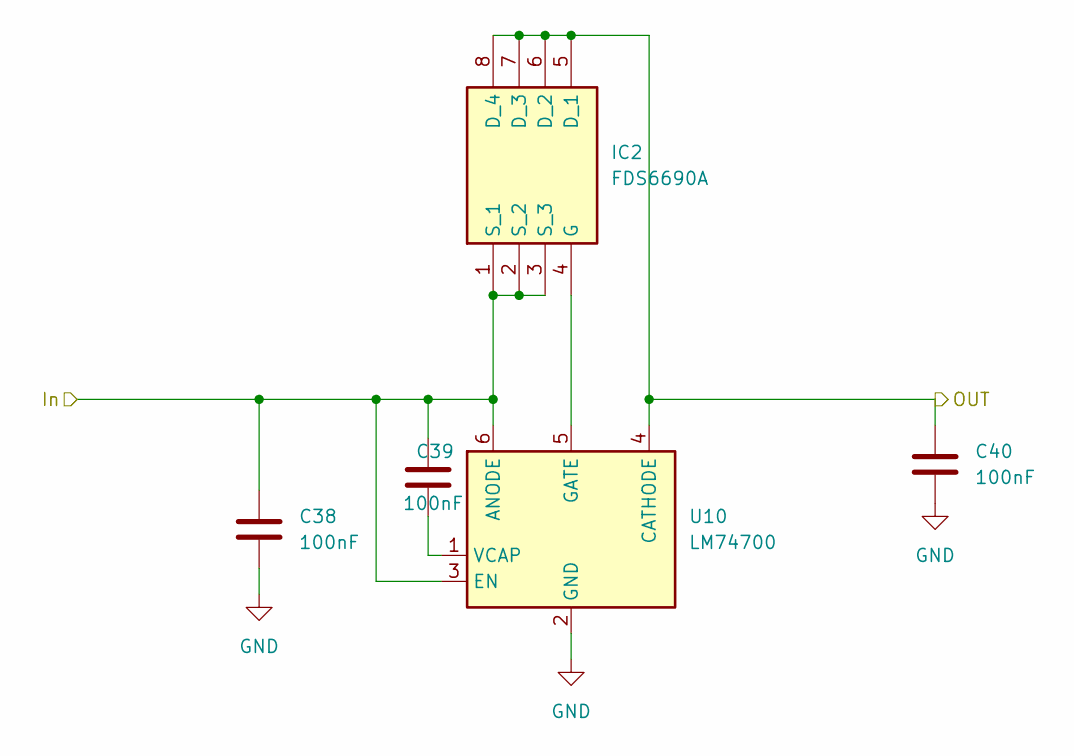
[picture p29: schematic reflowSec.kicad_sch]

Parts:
C38, C39, C40: 100nF; C_0805_2012Metric_Pad1.18x1.45mm_HandSolder
IC2: FDS6690A; SOIC127P600X175-8N; Mouser Part Number 512-FDS6690A
U10: LM74700; SOT-23-6

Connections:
/5V: C40.1, IC2.5 (D_1), IC2.6 (D_2), IC2.7 (D_3), IC2.8 (D_4), U10.4 (CATHODE); also elsewhere on the board
/LoVolConversion/5V_UNSEC: C38.1, C39.1, IC2.1 (S_1), IC2.2 (S_2), IC2.3 (S_3), U10.3 (EN), U10.6 (ANODE); also elsewhere on the board
GND: C38.2, C40.2, U10.2 (GND); also elsewhere on the board
unnamed: IC2.4 (G), U10.5 (GATE)
unnamed: C39.2, U10.1 (VCAP)

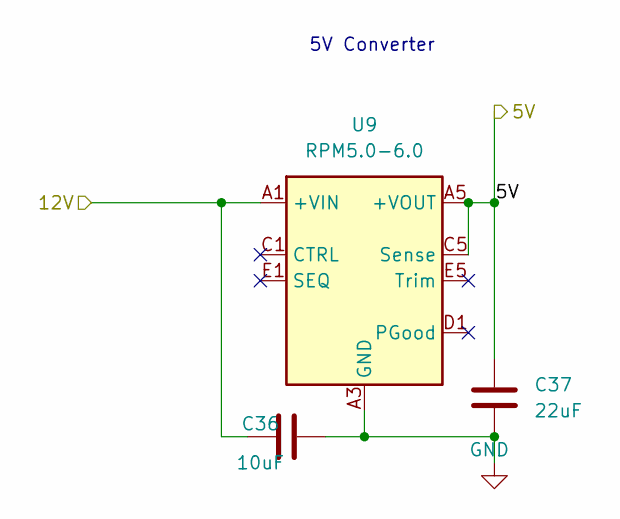
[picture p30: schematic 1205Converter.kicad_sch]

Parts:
C36: 10uF; C_0805_2012Metric_Pad1.18x1.45mm_HandSolder
C37: 22uF; C_0805_2012Metric_Pad1.18x1.45mm_HandSolder
U9: RPM5.0-6.0; Converter_DCDC_RECOM_RPMx.x-x.0

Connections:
/12V: C36.1, U9.A1 (+VIN), U9.A2 (+VIN); also elsewhere on the board
/LoVolConversion/5V_UNSEC: C37.1, U9.A5 (+VOUT), U9.B5 (+VOUT), U9.C5 (Sense); also elsewhere on the board
GND: C36.2, C37.2, U9.A3 (GND), U9.A4 (GND), U9.B1 (GND), U9.B2 (GND), U9.B3 (GND), U9.B4 (GND), U9.C2 (GND), U9.C3 (GND), U9.C4 (GND), U9.D2 (GND), U9.D3 (GND), U9.D4 (GND), U9.D5 (GND), U9.E3 (GND), U9.E4 (GND); also elsewhere on the board

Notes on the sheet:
5V Converter

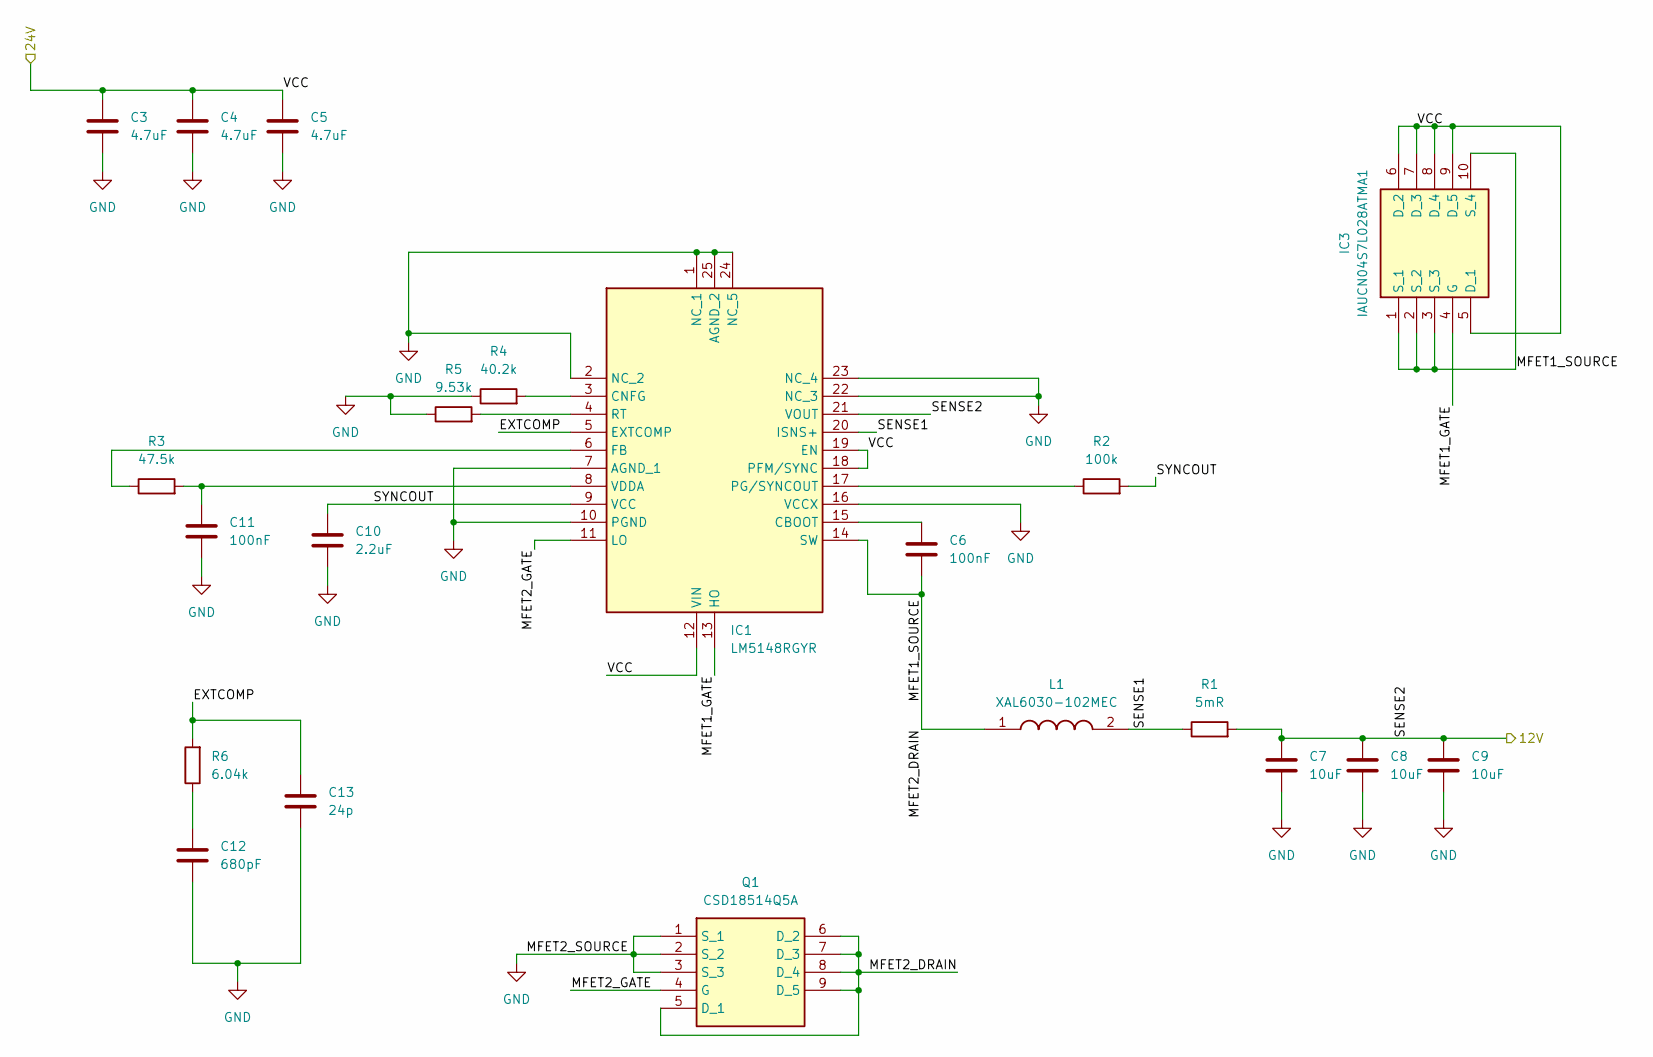
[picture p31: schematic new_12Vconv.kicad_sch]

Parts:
C3, C4, C5: 4.7uF; C_0805_2012Metric_Pad1.18x1.45mm_HandSolder
C6, C11: 100nF; C_0805_2012Metric_Pad1.18x1.45mm_HandSolder
C7, C8, C9: 10uF; C_0805_2012Metric_Pad1.18x1.45mm_HandSolder
C10: 2.2uF; C_0805_2012Metric_Pad1.18x1.45mm_HandSolder
C12: 680pF; C_0805_2012Metric_Pad1.18x1.45mm_HandSolder
C13: 24p; C_0805_2012Metric_Pad1.18x1.45mm_HandSolder
IC1: LM5148RGYR; Mouser Part Number 595-LM5148RGYR
IC3: IAUCN04S7L028ATMA1; IAUC120N06S5N011ATMA1; Mouser Part Number 726-IAUCN04S7L028ATM
L1: XAL6030-102MEC; XAL6030102MEC; Mouser Part Number 994-XAL6030-102MEC
Q1: CSD18514Q5A; Mouser Part Number 595-CSD18514Q5A
R1: 5mR; R_Axial_DIN0414_L11.9mm_D4.5mm_P15.24mm_Horizontal
R2: 100k; R_0805_2012Metric_Pad1.20x1.40mm_HandSolder
R3: 47.5k; R_0805_2012Metric_Pad1.20x1.40mm_HandSolder
R4: 40.2k; R_0805_2012Metric_Pad1.20x1.40mm_HandSolder
R5: 9.53k; R_0805_2012Metric_Pad1.20x1.40mm_HandSolder
R6: 6.04k; R_0805_2012Metric_Pad1.20x1.40mm_HandSolder

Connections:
/12V_PC: C7.1, C8.1, C9.1, IC1.21 (VOUT), R1.2; also elsewhere on the board
/24V: C3.1, C4.1, C5.1, IC1.12 (VIN), IC1.18 (PFM/SYNC), IC1.19 (EN), IC3.5 (D_1), IC3.6 (D_2), IC3.7 (D_3), IC3.8 (D_4), IC3.9 (D_5); also elsewhere on the board
/HiVolConversion/2412Converter/new_12V/EXTCOMP: C13.1, IC1.5 (EXTCOMP), R6.2
/HiVolConversion/2412Converter/new_12V/MFET1_GATE: IC1.13 (HO), IC3.4 (G)
/HiVolConversion/2412Converter/new_12V/MFET1_SOURCE: C6.2, IC1.14 (SW), IC3.1 (S_1), IC3.2 (S_2), IC3.3 (S_3), IC3.10 (S_4), L1.1, Q1.5 (D_1), Q1.6 (D_2), Q1.7 (D_3), Q1.8 (D_4), Q1.9 (D_5)
/HiVolConversion/2412Converter/new_12V/MFET2_GATE: IC1.11 (LO), Q1.4 (G)
/HiVolConversion/2412Converter/new_12V/SENSE1: IC1.20 (ISNS+), L1.2, R1.1
/HiVolConversion/2412Converter/new_12V/SYNCOUT: C10.1, IC1.9 (VCC), R2.2
GND: C3.2, C4.2, C5.2, C7.2, C8.2, C9.2, C10.2, C11.2, C12.2, C13.2, IC1.1 (NC_1), IC1.2 (NC_2), IC1.7 (AGND_1), IC1.10 (PGND), IC1.16 (VCCX), IC1.22 (NC_3), IC1.23 (NC_4), IC1.24 (NC_5), IC1.25 (AGND_2), Q1.1 (S_1), Q1.2 (S_2), Q1.3 (S_3), R4.1, R5.1; also elsewhere on the board
unnamed: C12.1, R6.1
unnamed: C6.1, IC1.15 (CBOOT)
unnamed: IC1.3 (CNFG), R4.2
unnamed: IC1.6 (FB), R3.1
unnamed: IC1.17 (PG/SYNCOUT), R2.1
unnamed: IC1.4 (RT), R5.2
unnamed: C11.1, IC1.8 (VDDA), R3.2

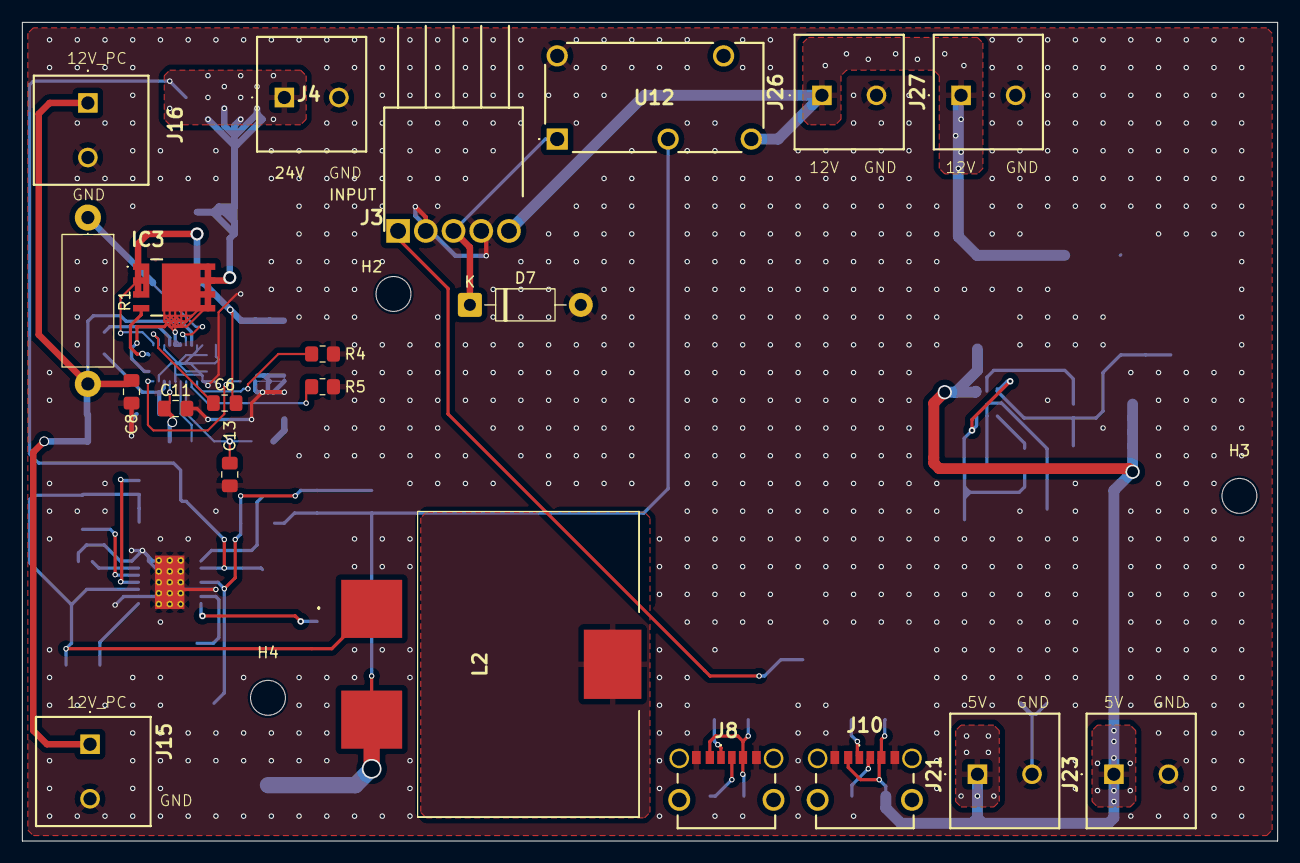
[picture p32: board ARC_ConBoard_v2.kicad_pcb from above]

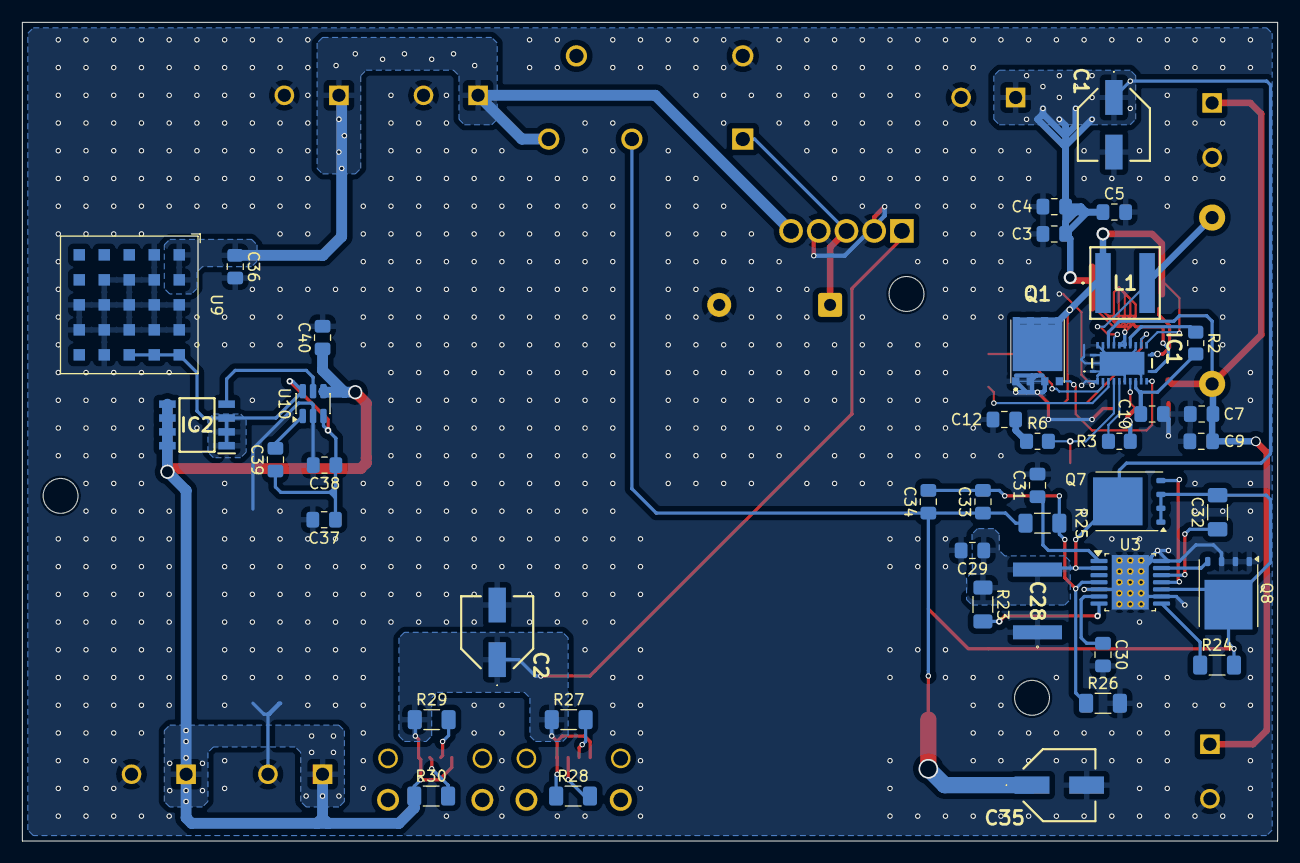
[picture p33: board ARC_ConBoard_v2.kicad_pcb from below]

Board: 2 copper layers, 115.0 x 75.0 mm, 66 parts (42 on the bottom side), 36 nets.

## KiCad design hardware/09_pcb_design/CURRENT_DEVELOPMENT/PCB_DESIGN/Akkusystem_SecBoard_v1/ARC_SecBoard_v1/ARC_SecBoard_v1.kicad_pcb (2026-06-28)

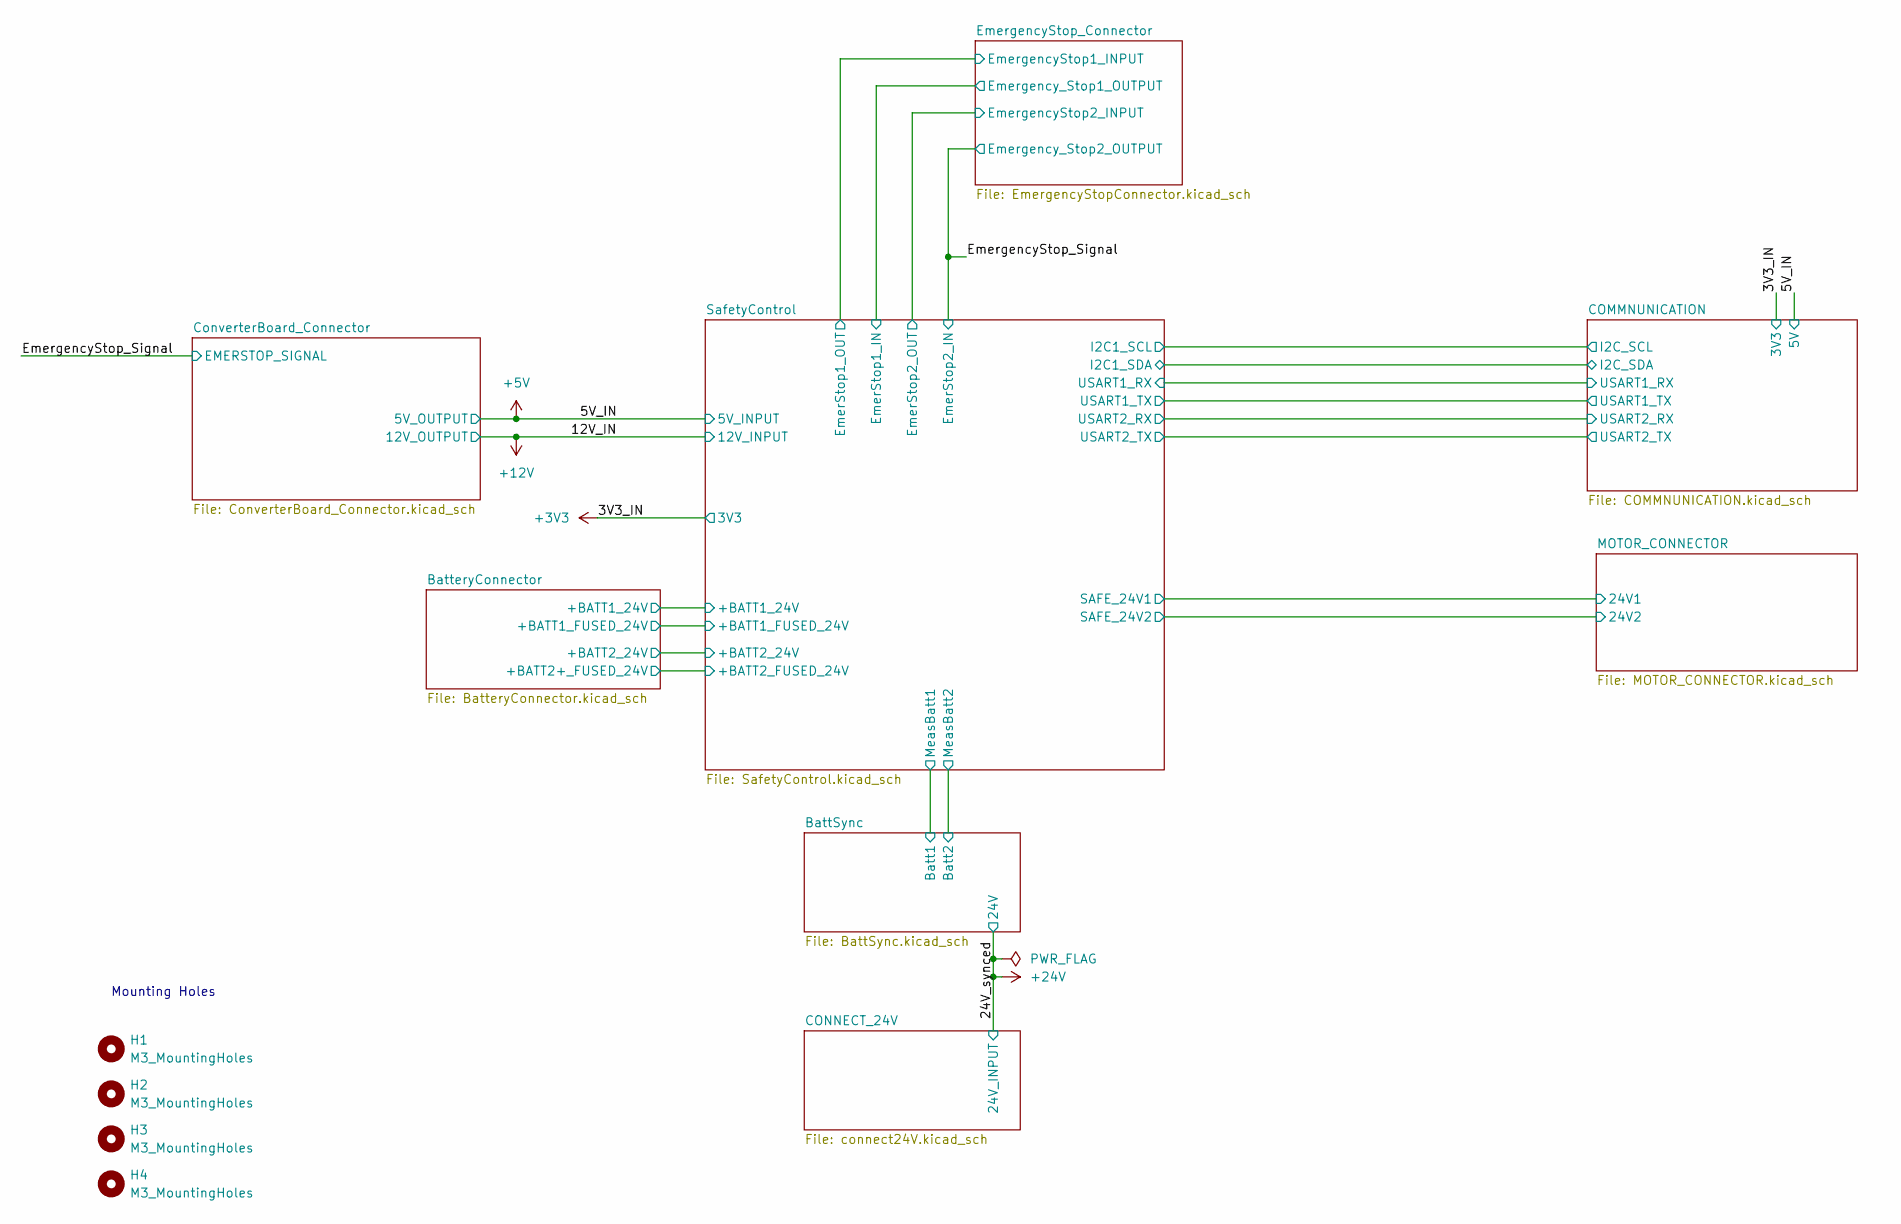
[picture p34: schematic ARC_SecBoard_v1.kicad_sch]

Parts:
H1, H2, H3, H4: M3_MountingHoles; MountingHole_3.2mm_M3

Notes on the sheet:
Mounting Holes


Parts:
C13, C21, C22, C23, C24, C25: ESY106M035AB2AA; CAPPRD150W45D400H850; Mouser Part Number 80-ESY106M035AB2AA
J6, J7, J8, J9, J10, J11: VP026584000AG; SHDR4W100P1016_2X2_2032X1830X2850P; Manufacturer_Part_Number VP026584000AG; Mouser Part Number 523-VP026584000AG
J12: 25SH-B-02-TR; 25SHB02TR; Manufacturer_Part_Number 25SH-B-02-TR

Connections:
/MOTOR_CONNECTOR/24V1: C13.1 (+), C21.1 (+), C22.1 (+), J6.1, J6.2, J7.1, J7.2, J8.1, J8.2; also elsewhere on the board
/MOTOR_CONNECTOR/24V2: C23.1 (+), C24.1 (+), C25.1 (+), J9.1, J9.2, J10.1, J10.2, J11.1, J11.2, J12.2; also elsewhere on the board
GND: C13.2 (-), C21.2 (-), C22.2 (-), C23.2 (-), C24.2 (-), C25.2 (-), J6.3, J6.4, J7.3, J7.4, J8.3, J8.4, J9.3, J9.4, J10.3, J10.4, J11.3, J11.4, J12.1; also elsewhere on the board

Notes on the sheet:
INPUTS
LIDAR
Motor Connectors Left Side Unitree
Motor Connectors Right Side Unitree


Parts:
BAT1_INPUT1, BAT2_INPUT1: VP026584000AG; SHDR4W100P1016_2X2_2032X1830X2850P; Manufacturer_Part_Number VP026584000AG; Mouser Part Number 523-VP026584000AG
FUSEHOLDER1, FUSEHOLDER2: 30A; 17867640001; Manufacturer_Part_Number 178.6764.0001; Mouser Part Number 576-178.6764.0001

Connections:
/BatteryConnector/+BATT1_24V: BAT1_INPUT1.1, BAT1_INPUT1.2, FUSEHOLDER1.1; also elsewhere on the board
/BatteryConnector/+BATT1_FUSED_24V: FUSEHOLDER1.2; also elsewhere on the board
/BatteryConnector/+BATT2_24V: BAT2_INPUT1.1, BAT2_INPUT1.2, FUSEHOLDER2.1; also elsewhere on the board
/BatteryConnector/+BATT2_FUSED_24V: FUSEHOLDER2.2; also elsewhere on the board
GND: BAT1_INPUT1.3, BAT1_INPUT1.4, BAT2_INPUT1.3, BAT2_INPUT1.4; also elsewhere on the board

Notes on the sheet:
BATTERY FUSES
BATTERY CONNECTOR


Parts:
J3: 640455-5; HDRRA5W88P0X254_1X5_1270X775X610P; Mouser Part Number 571-6404555

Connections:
+5V: J3.1; also elsewhere on the board
+12V: J3.5; also elsewhere on the board
/EmergencyStop_Signal: J3.3; also elsewhere on the board
GND: J3.2, J3.4; also elsewhere on the board

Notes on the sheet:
Converter Board Connector
Connections to the Top Board. 5V/12V Supply from the Converter and Emergency Stop signal from the Bottom board (this Board)


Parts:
J1: EmerStop_Con1; 25SHB02TR; PARTREV N/A
J2: EmerStop_Con2; 25SHB02TR; PARTREV N/A

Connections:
/BattSync/MEAS_BATT1_24V: J1.1; also elsewhere on the board
/BattSync/MEAS_BATT2_24V: J2.1; also elsewhere on the board
/EmergencyStop_Connector/EmerStop_1_OUTPUT: J1.2; also elsewhere on the board
/EmergencyStop_Signal: J2.2; also elsewhere on the board

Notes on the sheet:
NOT-AUS-Trenner

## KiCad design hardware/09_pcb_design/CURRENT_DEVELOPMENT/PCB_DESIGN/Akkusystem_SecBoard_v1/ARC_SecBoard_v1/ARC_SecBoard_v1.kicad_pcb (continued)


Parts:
J4, J5: 1792863; Mouser Part Number 651-1792863

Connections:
+24V: J4.1, J5.1; also elsewhere on the board
GND: J4.2, J5.2; also elsewhere on the board

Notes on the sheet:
INPUT
Board Outputs 24V


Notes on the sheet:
Converter INPUTS
Not-Aus-Trenner
Board Inputs


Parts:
IC7: PI4ULS5V202UEX; SOP65P490X110-8N; Mouser Part Number 729-PI4ULS5V202UEX
J22: B4B-XH-A_LF__SN_; B4BXHALFSN; Mouser Part Number 306-B4BXHALFSN
J28: 25SHB02TR; PARTREV N/A
J37: B2B-XH-A__LF__SN_; 25SHB02TR; PARTREV N/A
R32: 10k; R_1206_3216Metric_Pad1.30x1.75mm_HandSolder

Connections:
+3V3: IC7.1 (VCCA), J22.4, R32.1; also elsewhere on the board
+5V: IC7.8 (VCCB); also elsewhere on the board
/COMMNUNICATION/I2C1_SCL: J22.2; also elsewhere on the board
/COMMNUNICATION/I2C1_SDA: J22.1; also elsewhere on the board
/COMMNUNICATION/USART1_RX: J28.2; also elsewhere on the board
/COMMNUNICATION/USART1_TX: J28.1; also elsewhere on the board
/COMMNUNICATION/USART2_RX: IC7.2 (A1); also elsewhere on the board
/COMMNUNICATION/USART2_TX: IC7.3 (A2); also elsewhere on the board
GND: IC7.4 (GND), J22.3; also elsewhere on the board
unnamed: IC7.7 (B1), J37.1
unnamed: IC7.6 (B2), J37.2
unnamed: IC7.5 (EN), R32.2

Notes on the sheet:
SUPP VOLTAGES
UART 3V3
UART 5V
OLED-Display

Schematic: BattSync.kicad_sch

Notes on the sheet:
OUTPUTS
INPUTS
Battery Sync with ideal Diode

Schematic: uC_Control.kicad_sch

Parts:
C14, C42: 47nF; C_0805_2012Metric_Pad1.18x1.45mm_HandSolder
R31, R33: 10k; R_1206_3216Metric_Pad1.30x1.75mm_HandSolder
U4: NUCLEO-L432KC; MODULE_NUCLEO-L432KC; PARTREV N/A

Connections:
+3V3: C14.1, R31.1, R33.1, U4.CN4_14 (+3V3); also elsewhere on the board
+5V: C42.1, U4.CN4_4 (+5V); also elsewhere on the board
+12V: U4.CN4_1 (VIN); also elsewhere on the board
/COMMNUNICATION/I2C1_SCL: R31.2, U4.CN3_8 (PB6); also elsewhere on the board
/COMMNUNICATION/I2C1_SDA: R33.2, U4.CN3_7 (PB7); also elsewhere on the board
/COMMNUNICATION/USART1_RX: U4.CN3_2 (PA10); also elsewhere on the board
/COMMNUNICATION/USART1_TX: U4.CN3_1 (PA9); also elsewhere on the board
/COMMNUNICATION/USART2_RX: U4.CN4_10 (PA3); also elsewhere on the board
/COMMNUNICATION/USART2_TX: U4.CN4_5 (PA2); also elsewhere on the board
/SafetyControl/Current Measurement/meas_bat11: U4.CN4_12 (PA0); also elsewhere on the board
/SafetyControl/Current Measurement/meas_bat12: U4.CN4_11 (PA1); also elsewhere on the board
/SafetyControl/Current Measurement/meas_bat21: U4.CN4_8 (PA5); also elsewhere on the board
/SafetyControl/Current Measurement/meas_bat22: U4.CN4_7 (PA6); also elsewhere on the board
/SafetyControl/Current Measurement/meas_curmeas1: U4.CN4_9 (PA4); also elsewhere on the board
/SafetyControl/Current Measurement/meas_curmeas2: U4.CN4_6 (PA7); also elsewhere on the board
/SafetyControl/IO_STM_1: U4.CN3_12 (PA8); also elsewhere on the board
/SafetyControl/IO_STM_2: U4.CN3_15 (PB4); also elsewhere on the board
GND: C14.2, C42.2, U4.CN3_4 (GND_CN3), U4.CN4_2 (GND_CN4); also elsewhere on the board

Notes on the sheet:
STM32
VOLTAGE

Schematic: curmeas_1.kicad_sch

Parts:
C1, C2, C3, C4, C11, C12: 1uF; C_0805_2012Metric_Pad1.18x1.45mm_HandSolder
C5, C8: 4.7nF; C_0805_2012Metric_Pad1.18x1.45mm_HandSolder
C6, C7, C9, C10: 47nF; C_0805_2012Metric_Pad1.18x1.45mm_HandSolder
CurMeas_BATT1, CurMeas_BATT2: HLSR_16-P; HLSR16P; Manufacturer_Part_Number HLSR 16-P
R1, R3, R5, R7: 6k8; R_1206_3216Metric_Pad1.30x1.75mm_HandSolder
R2, R4, R6, R8: 1k; R_1206_3216Metric_Pad1.30x1.75mm_HandSolder
R9, R11: 5k1; R_1206_3216Metric_Pad1.30x1.75mm_HandSolder
R10, R12: 10k; R_1206_3216Metric_Pad1.30x1.75mm_HandSolder

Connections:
+5V: C9.1, C10.1, CurMeas_BATT1.4 (+UC), CurMeas_BATT2.4 (+UC); also elsewhere on the board
/BattSync/MEAS_BATT1_24V: CurMeas_BATT1.5 (IP-_1), CurMeas_BATT1.6 (IP-_2), CurMeas_BATT1.7 (IP-_3); also elsewhere on the board
/BattSync/MEAS_BATT2_24V: CurMeas_BATT2.5 (IP-_1), CurMeas_BATT2.6 (IP-_2), CurMeas_BATT2.7 (IP-_3); also elsewhere on the board
/BatteryConnector/+BATT1_24V: R1.1; also elsewhere on the board
/BatteryConnector/+BATT1_FUSED_24V: CurMeas_BATT1.8 (IP+_1), CurMeas_BATT1.9 (IP+_2), CurMeas_BATT1.10 (IP+_3), R5.1; also elsewhere on the board
/BatteryConnector/+BATT2_24V: R3.1; also elsewhere on the board
/BatteryConnector/+BATT2_FUSED_24V: CurMeas_BATT2.8 (IP+_1), CurMeas_BATT2.9 (IP+_2), CurMeas_BATT2.10 (IP+_3), R7.1; also elsewhere on the board
/SafetyControl/Current Measurement/BATT1_CurMeas_VOUT: C5.1, CurMeas_BATT1.2 (VOUT), R9.1
/SafetyControl/Current Measurement/BATT2_CurMeas_VOUT: C8.1, CurMeas_BATT2.2 (VOUT), R11.1
/SafetyControl/Current Measurement/meas_bat11: C1.1, R1.2, R2.1; also elsewhere on the board
/SafetyControl/Current Measurement/meas_bat12: C3.1, R5.2, R6.1; also elsewhere on the board
/SafetyControl/Current Measurement/meas_bat21: C2.1, R3.2, R4.1; also elsewhere on the board
/SafetyControl/Current Measurement/meas_bat22: C4.1, R7.2, R8.1; also elsewhere on the board
/SafetyControl/Current Measurement/meas_curmeas1: C11.1, R9.2, R10.1; also elsewhere on the board
/SafetyControl/Current Measurement/meas_curmeas2: C12.1, R11.2, R12.1; also elsewhere on the board
GND: C1.2, C2.2, C3.2, C4.2, C5.2, C6.2, C7.2, C8.2, C9.2, C10.2, C11.2, C12.2, CurMeas_BATT1.3 (GND-OR_0V), CurMeas_BATT2.3 (GND-OR_0V), R2.2, R4.2, R6.2, R8.2, R10.2, R12.2; also elsewhere on the board
unnamed: C6.1, CurMeas_BATT1.1 (VREF(IN/OUT))
unnamed: C7.1, CurMeas_BATT2.1 (VREF(IN/OUT))

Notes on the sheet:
VOLTAGEDIVIDER 5V<3V3
CURRENT MEASURING
VOLTAGEDIVIDER 1

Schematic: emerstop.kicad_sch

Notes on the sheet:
OnOff Curcuit

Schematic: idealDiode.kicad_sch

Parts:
C15, C17, C18, C20: 100nF; C_0805_2012Metric_Pad1.18x1.45mm_HandSolder
C16, C19: 0.1uF; C_0805_2012Metric_Pad1.18x1.45mm_HandSolder
D4, D5: SMBJ26A-E3_52; DIOM5436X244N; Mouser Part Number 625-SMBJ26A-E3
IC1, IC4: FDS6690A; SOIC127P600X175-8N; Mouser Part Number 512-FDS6690A
U2, U7: LM74700; SOT-23-6

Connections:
+24V: C17.1, C20.1, IC1.5 (D_1), IC1.6 (D_2), IC1.7 (D_3), IC1.8 (D_4), IC4.5 (D_1), IC4.6 (D_2), IC4.7 (D_3), IC4.8 (D_4), U2.4 (CATHODE), U7.4 (CATHODE); also elsewhere on the board
/BattSync/MEAS_BATT1_24V: C15.1, C16.1, D4.1 (K), IC4.1 (S_1), IC4.2 (S_2), IC4.3 (S_3), U7.3 (EN), U7.6 (ANODE); also elsewhere on the board
/BattSync/MEAS_BATT2_24V: C18.1, C19.1, D5.1 (K), IC1.1 (S_1), IC1.2 (S_2), IC1.3 (S_3), U2.3 (EN), U2.6 (ANODE); also elsewhere on the board
GND: C15.2, C17.2, C18.2, C20.2, D4.2 (A), D5.2 (A), U2.2 (GND), U7.2 (GND); also elsewhere on the board
unnamed: IC1.4 (G), U2.5 (GATE)
unnamed: IC4.4 (G), U7.5 (GATE)
unnamed: C19.2, U2.1 (VCAP)
unnamed: C16.2, U7.1 (VCAP)

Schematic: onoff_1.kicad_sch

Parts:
D3: 1N4007; D_DO-41_SOD81_P10.16mm_Horizontal
D6: BZX84Cxx; SOT-23
K1: T9AS1D12-24; T9AS1D1224; Mouser Part Number 655-T9AS1D12-24
Q3: IPD70P04P4L08ATMA2; Mouser Part Number 726-IPD70P04P4L08ATM
Q6: BSS138; SOT-23
R17: 100kOhm; R_1206_3216Metric_Pad1.30x1.75mm_HandSolder
R18: 5k1; R_1206_3216Metric_Pad1.30x1.75mm_HandSolder

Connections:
/BattSync/MEAS_BATT1_24V: K1.4 (NO); also elsewhere on the board
/EmergencyStop_Connector/EmerStop_1_OUTPUT: D3.1 (K), K1.2 (COIL_2); also elsewhere on the board
/MOTOR_CONNECTOR/24V1: Q3.2 (D); also elsewhere on the board
/SafetyControl/IO_STM_1: Q6.1 (G); also elsewhere on the board
GND: D3.2 (A), K1.1 (COIL_1), Q6.2 (S); also elsewhere on the board
unnamed: D6.1 (A), Q3.1 (G), R17.2, R18.2
unnamed: D6.3 (K), K1.3 (COM), Q3.3 (S), R17.1
unnamed: Q6.3 (D), R18.1

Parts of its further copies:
D1: 1N4007; D_DO-41_SOD81_P10.16mm_Horizontal
D2: BZX84Cxx; SOT-23
K2: T9AS1D12-24; T9AS1D1224; Mouser Part Number 655-T9AS1D12-24
Q1: BSS138; SOT-23
Q2: IPD70P04P4L08ATMA2; Mouser Part Number 726-IPD70P04P4L08ATM
R13: 100kOhm; R_1206_3216Metric_Pad1.30x1.75mm_HandSolder
R14: 5k1; R_1206_3216Metric_Pad1.30x1.75mm_HandSolder

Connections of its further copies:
/BattSync/MEAS_BATT2_24V: K2.4 (NO); also elsewhere on the board
/EmergencyStop_Signal: D1.1 (K), K2.2 (COIL_2); also elsewhere on the board
/MOTOR_CONNECTOR/24V2: Q2.2 (D); also elsewhere on the board
/SafetyControl/IO_STM_2: Q1.1 (G); also elsewhere on the board
GND: D1.2 (A), K2.1 (COIL_1), Q1.2 (S); also elsewhere on the board
unnamed: D2.1 (A), Q2.1 (G), R13.2, R14.2
unnamed: D2.3 (K), K2.3 (COM), Q2.3 (S), R13.1
unnamed: Q1.3 (D), R14.1



Board: 2 copper layers, 135.0 x 90.0 mm, 88 parts (52 on the bottom side), 46 nets.

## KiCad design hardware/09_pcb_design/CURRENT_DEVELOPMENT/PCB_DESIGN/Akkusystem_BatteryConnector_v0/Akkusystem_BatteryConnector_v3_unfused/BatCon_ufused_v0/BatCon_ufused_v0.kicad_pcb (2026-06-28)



Board: 2 copper layers, 29.5 x 42.0 mm, 6 parts (2 on the bottom side), 2 nets, no tracks yet.

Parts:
H1, H2: M2; MountingHole_3.2mm_M3_DIN965
J1, J2, J3, J4: 19705-4201; 197054201

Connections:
+24V: J1.1, J1.2, J3.1, J3.2
GND: J2.1, J2.2, J4.1, J4.2

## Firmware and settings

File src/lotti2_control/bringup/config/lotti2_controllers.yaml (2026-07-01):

controller_manager:
  ros__parameters:
    update_rate: 50 #Hz

    joint_state_broadcaster:
      type: joint_state_broadcaster/JointStateBroadcaster
      
    lotti2_arm_group_controller:
      type: joint_trajectory_controller/JointTrajectoryController
      is_async: true
      update_rate: 20

    lotti2_flipper_controller:
      type: lotti2_flipper_controller/FlipperController
      is_async: true
      update_rate: 25

    lotti2_drive_controller:
      type: diff_drive_controller/DiffDriveController
      update_rate: 50



lotti2_flipper_controller:
  ros__parameters:
    joints:
    - flipper_fr_joint
    - flipper_fl_joint
    - flipper_rr_joint
    - flipper_rl_joint
    command_interfaces:
    - position
    - velocity
    state_interfaces:
    - position
    - effort
    - velocity
    - temp



lotti2_drive_controller:
  ros__parameters:
    left_wheel_names: ["left_chain_joint"]
    right_wheel_names: ["right_chain_joint"]

    wheel_separation: 0.30
    wheel_radius: 0.11

    wheel_separation_multiplier: 4.0
    left_wheel_radius_multiplier: 1.0
    right_wheel_radius_multiplier: 1.0

    publish_rate: 50.0
    #odom_frame_id: odom
    #base_frame_id: body_link
    #pose_covariance_diagonal : [0.001, 0.001, 0.001, 0.001, 0.001, 0.01]
    #twist_covariance_diagonal: [0.001, 0.001, 0.001, 0.001, 0.001, 0.01]

    open_loop: true
    enable_odom_tf: false

    cmd_vel_timeout: 100.0
    #velocity_rolling_window_size: 10

    # Velocity and acceleration limits
    # Whenever a min_* is unspecified, default to -max_*
    linear.x.max_velocity: 0.1     
    linear.x.max_acceleration: 0.1  
    linear.x.max_jerk: NAN

    angular.z.max_velocity: 0.1
    angular.z.max_acceleration: 0.1
    angular.z.max_jerk: NAN



lotti2_arm_group_controller:
  ros__parameters:
    joints:
    - arm1_joint
    - arm2_joint
    - arm3_joint
    - arm4_joint
    - arm5_joint
    - arm6_joint
    - arm7_joint
    command_interfaces:
    - velocity
    state_interfaces:
    - velocity
    - position

    allow_partial_joints_goal: true
    open_loop_control: true
    interpolate_from_desired_state: true
    set_last_command_interface_value_as_state_on_activation: false
    allow_nonzero_velocity_at_trajectory_end: true
    constraints:
      stopped_velocity_tolerance: 0.01
      goal_time: 0.05

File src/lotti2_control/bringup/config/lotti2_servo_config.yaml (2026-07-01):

###############################################
# Modify all parameters related to servoing here
###############################################
use_gazebo: false # Whether the robot is started in a Gazebo simulation environment

## Properties of incoming commands
command_in_type: "unitless" # "unitless"> in the range [-1:1], as if from joystick. "speed_units"> cmds are in m/s and rad/s
scale:
  # Scale parameters are only used if command_in_type=="unitless"
  linear:  0.5  # Max linear velocity. Unit is [m/s]. Only used for Cartesian commands.
  rotational:  1.5 # Max angular velocity. Unit is [rad/s]. Only used for Cartesian commands.
  # Max joint angular/linear velocity. Only used for joint commands on joint_command_in_topic.
  joint: 2.0


# Optionally override Servo's internal velocity scaling when near singularity or collision (0.0 = use internal velocity scaling)
override_velocity_scaling_factor: 0.5 # valid range [0.0:1.0]

## Properties of outgoing commands
publish_period: 0.05  # 1/Nominal publish rate [seconds]
low_latency_mode: false  # Set this to true to publish as soon as an incoming Twist command is received (publish_period is ignored)
max_expected_latency: 0.5

# What type of topic does your robot driver expect?
# Currently supported are std_msgs/Float64MultiArray or trajectory_msgs/JointTrajectory
command_out_type: trajectory_msgs/JointTrajectory

# What to publish? Can save some bandwidth as most robots only require positions or velocities
publish_joint_positions: true
publish_joint_velocities: true
publish_joint_accelerations: false

## Plugins for smoothing outgoing commands
use_smoothing: true
smoothing_filter_plugin_name: "online_signal_smoothing::ButterworthFilterPlugin"

# If is_primary_planning_scene_monitor is set to true, the Servo server's PlanningScene advertises the /get_planning_scene service,
# which other nodes can use as a source for information about the planning environment.
# NOTE: If a different node in your system is responsible for the "primary" planning scene instance (e.g. the MoveGroup node),
# then is_primary_planning_scene_monitor needs to be set to false.
is_primary_planning_scene_monitor: true
check_octomap_collisions: false 

## MoveIt properties
move_group_name: lotti_arm_group  # Often 'manipulator' or 'arm'
planning_frame: body_link  # The MoveIt planning frame. Often 'base_link' or 'world'

## Other frames
ee_frame_name: arm7_link  # The name of the end effector link, used to return the EE pose
robot_link_command_frame: arm6_link  # commands must be given in the frame of a robot link. Usually either the base or end effector

## Stopping behaviour
incoming_command_timeout:  5.0  # Stop servoing if X seconds elapse without a new command
# If 0, republish commands forever even if the robot is stationary. Otherwise, specify num. to publish.
# Important because ROS may drop some messages and we need the robot to halt reliably.
num_outgoing_halt_msgs_to_publish: 4

## Configure handling of singularities and joint limits
lower_singularity_threshold:  70.0  # Start decelerating when the condition number hits this (close to singularity)
hard_stop_singularity_threshold: 100.0 # Stop when the condition number hits this
joint_limit_margin: 0.05 # added as a buffer to joint limits [radians]. If moving quickly, make this larger.
leaving_singularity_threshold_multiplier: 1.0 # Multiply the hard stop limit by this when leaving singularity (see https://github.com/ros-planning/moveit2/pull/620)

## Topic names
pose_command_in_topic: cmd/arm/position # Topic for incomming position commands
cartesian_command_in_topic: cmd/arm/joy_twiststamped  # Topic for incoming Cartesian twist commands
joint_command_in_topic: cmd/arm/joy_joint # Topic for incoming joint angle commands
joint_topic: /joint_states
status_topic: ~/status # Publish status to this topic
command_out_topic: /lotti2_arm_group_controller/joint_trajectory # Publish outgoing commands here

## Collision checking for the entire robot body
check_collisions: false # Check collisions?
collision_check_rate: 10.0 # [Hz] Collision-checking can easily bog down a CPU if done too often.
self_collision_proximity_threshold: 0.01 # Start decelerating when a self-collision is this far [m]
scene_collision_proximity_threshold: 0.02 # Start decelerating when a scene collision is this far [m]

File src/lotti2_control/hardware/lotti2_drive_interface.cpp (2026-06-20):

// Based on:

// Copyright 2021 ros2_control Development Team
//
// Licensed under the Apache License, Version 2.0 (the "License");
// you may not use this file except in compliance with the License.
// You may obtain a copy of the License at
//
//     http://www.apache.org/licenses/LICENSE-2.0
//
// Unless required by applicable law or agreed to in writing, software
// distributed under the License is distributed on an "AS IS" BASIS,
// WITHOUT WARRANTIES OR CONDITIONS OF ANY KIND, either express or implied.
// See the License for the specific language governing permissions and
// limitations under the License.

// Changes made to the example by the Res.Q Bots Austria Team
// of Vienna University of Applied Sciences

#include "lotti2_control/lotti2_drive_interface.hpp"
// general purpose
#include <chrono>
#include <cmath>
#include <cstddef>
#include <iomanip>
#include <limits>
#include <memory>
#include <sstream>
#include <vector>
// ros2_control
#include "hardware_interface/lexical_casts.hpp"
#include "hardware_interface/types/hardware_interface_type_values.hpp"
#include "rclcpp/rclcpp.hpp"
// hardware
#include <unistd.h>
#include "lotti2_control/cubeMars_motor.h"
#include "lotti2_control/drive_comms.hpp"

namespace lotti2_drive_interface {
hardware_interface::CallbackReturn DriveInterface::on_init(
  const hardware_interface::HardwareComponentInterfaceParams& params) {
    if (hardware_interface::SystemInterface::on_init(params) !=
        hardware_interface::CallbackReturn::SUCCESS) {
        return hardware_interface::CallbackReturn::ERROR;
    }

    // get the parameters from the ros2_control file
    device_       = info_.hardware_parameters["device"].c_str();
    e_conv_       = stof(info_.hardware_parameters["e_conversion"]);
    gear_ratio_   = stof(info_.hardware_parameters["gear_ratio"]);
    kt_           = stof(info_.hardware_parameters["Kt"]);
    max_vel_      = stof(info_.hardware_parameters["max_velocity"]);
    use_hardware_ = std::__cxx11::stoi(info_.hardware_parameters["use_hardware"]);
    if (!(use_hardware_ == 0 || use_hardware_ == 1)) {
        RCLCPP_ERROR(get_logger(), "DriveInterface: Invalid value for \"use_hardware\" in ros2_control file");
    }

    for (const hardware_interface::ComponentInfo& joint : info_.joints) {
        // DiffBotSystem has exactly two states and one command interface on each joint
        if (joint.command_interfaces.size() != 1) {
            RCLCPP_FATAL(
              get_logger(), "Joint '%s' has %zu command interfaces found. 1 expected.",
              joint.name.c_str(), joint.command_interfaces.size());
            return hardware_interface::CallbackReturn::ERROR;
        }

        if (joint.command_interfaces[0].name != hardware_interface::HW_IF_VELOCITY) {
            RCLCPP_FATAL(
              get_logger(), "Joint '%s' have %s command interfaces found. '%s' expected.",
              joint.name.c_str(), joint.command_interfaces[0].name.c_str(),
              hardware_interface::HW_IF_VELOCITY);
            return hardware_interface::CallbackReturn::ERROR;
        }

        if (joint.state_interfaces[0].name != hardware_interface::HW_IF_POSITION) {
            RCLCPP_FATAL(
              get_logger(), "Joint '%s' have '%s' as first state interface. '%s' expected.",
              joint.name.c_str(), joint.state_interfaces[0].name.c_str(),
              hardware_interface::HW_IF_POSITION);
            return hardware_interface::CallbackReturn::ERROR;
        }

        if (joint.state_interfaces[1].name != hardware_interface::HW_IF_VELOCITY) {
            RCLCPP_FATAL(
              get_logger(), "Joint '%s' have '%s' as second state interface. '%s' expected.",
              joint.name.c_str(), joint.state_interfaces[1].name.c_str(),
              hardware_interface::HW_IF_VELOCITY);
            return hardware_interface::CallbackReturn::ERROR;
        }
    }

    return hardware_interface::CallbackReturn::SUCCESS;
}

hardware_interface::CallbackReturn DriveInterface::on_configure(
  const rclcpp_lifecycle::State& /*previous_state*/) {
    // set default motor states
    for (std::size_t i = 0; i < info_.joints.size(); i++) {
        uint8_t motor_id;
        if (i == 0) {
            motor_id = 7;
        }
        else if (i == 1) {
            motor_id = 63;
        }
        motorStates_[i].motor_id = motor_id;
        // set all states to 0
        motorStates_[i].velocity   = 0.0;
        motorStates_[i].current    = 0.0;
        motorStates_[i].motor_temp = 0.0;
        motorStates_[i].error_code = 0;
        // set all commands to 0
        motorCommands_[i].motor_id = motor_id;
        motorCommands_[i].speed    = 0.0;
    }

    // always reset values when configuring hardware
    for (const auto& [name, descr] : joint_state_interfaces_) {
        set_state(name, 0.0);
    }
    for (const auto& [name, descr] : joint_command_interfaces_) {
        set_command(name, 0.0);
    }

    return hardware_interface::CallbackReturn::SUCCESS;
}

hardware_interface::CallbackReturn DriveInterface::on_cleanup(
  const rclcpp_lifecycle::State& /*previous_state*/) {
    return hardware_interface::CallbackReturn::SUCCESS;
}

hardware_interface::CallbackReturn DriveInterface::on_activate(
  const rclcpp_lifecycle::State& /*previous_state*/) {
    // only prepare can connection, if use_hardware is set to 1
    if (use_hardware_ == 1) {
        drive_comms_.open(device_);
    }

    // command and state should be equal when starting
    for (const auto& [name, descr] : joint_command_interfaces_) {
        set_command(name, get_state(name));
    }

    return hardware_interface::CallbackReturn::SUCCESS;
}

hardware_interface::CallbackReturn DriveInterface::on_deactivate(
  const rclcpp_lifecycle::State& /*previous_state*/) {
    // only necessary, if use_hardware is set to 1
    if (use_hardware_ == 1) {
        drive_comms_.close();
    }

    return hardware_interface::CallbackReturn::SUCCESS;
}
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

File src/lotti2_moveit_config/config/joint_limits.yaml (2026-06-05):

# joint_limits.yaml allows the dynamics properties specified in the URDF to be overwritten or augmented as needed

# For beginners, we downscale velocity and acceleration limits.
# You can always specify higher scaling factors (<= 1.0) in your motion requests.  # Increase the values below to 1.0 to always move at maximum speed.
default_velocity_scaling_factor: 0.1
default_acceleration_scaling_factor: 0.1

# Specific joint properties can be changed with the keys [max_position, min_position, max_velocity, max_acceleration]
# Joint limits can be turned off with [has_velocity_limits, has_acceleration_limits]
joint_limits:
  arm1_joint:
    has_velocity_limits: false
    max_velocity: 0
    has_acceleration_limits: false
    max_acceleration: 0
  arm2_joint:
    has_velocity_limits: false
    max_velocity: 0
    has_acceleration_limits: false
    max_acceleration: 0
  arm3_joint:
    has_velocity_limits: false
    max_velocity: 0
    has_acceleration_limits: false
    max_acceleration: 0
  arm4_joint:
    has_velocity_limits: false
    max_velocity: 0
    has_acceleration_limits: false
    max_acceleration: 0
  arm5_joint:
    has_velocity_limits: false
    max_velocity: 0
    has_acceleration_limits: false
    max_acceleration: 0
  arm6_joint:
    has_velocity_limits: false
    max_velocity: 0
    has_acceleration_limits: false
    max_acceleration: 0

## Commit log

2026-05-27 innitial commit
    [Lotti.srdf.xacro, Lotti.urdf.xacro, Lotti2.ros2_control.xacro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]
2026-05-29 camera implementation added
2026-05-29 CAD: Added Arm
    [17HE08-1004S.STEP, 17HE15-1504S.STEP, Aluprofil25x25.SLDPRT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]
2026-05-29 folder changed
    [17HE08-1004S.STEP, 17HE15-1504S.STEP, Aluprofil25x25.SLDPRT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]
2026-06-02 servo_node working
    [Lotti.urdf.xacro, Lotti2.ros2_control.xacro, Lotti2.urdf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]
2026-06-05 arm working
    [Lotti2.ros2_control.xacro, Lotti_arm.xacro, arm1_link.STL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]
2026-06-05 controllerbelegung angepasst
    [Lotti2.ros2_control.xacro, joint_limits.yaml, lotti2_servo_config.yaml]
2026-06-08 fix motor updates
    [Lotti2.ros2_control.xacro, lotti2_controllers.yaml, lotti2_servo_config.yaml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]
2026-06-09 nur noch umrechnungsfehler
    [Lotti2.ros2_control.xacro, lotti2_controllers.yaml, lotti2_servo_config.yaml]
2026-06-09 motors running!!
    [Lotti2.ros2_control.xacro, lotti2_controllers.yaml, lotti2_servo_config.yaml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]
2026-06-09 cleanup remainder of position steering
    [Lotti2.ros2_control.xacro]
2026-06-11 chains, flippers, arm moving. need to find kp, kd, dq for flippers and arm params.
    [Lotti2.ros2_control.xacro, Lotti_arm.xacro, lotti2_controllers.yaml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]
2026-06-12 drive testing
    [Lotti2.ros2_control.xacro, Lotti_arm.xacro, lotti2_controllers.yaml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]
2026-06-16 arm return to zero
    [Lotti2.ros2_control.xacro, lotti2_servo_config.yaml, ros2_controllers.yaml]
2026-06-16 Erster Upload CAD Body
    [000_BG_E-Passiv_montiert.SLDASM, 000_BG_Spannmechanismus_inkl. Montage.SLDASM, 000_Bg_E-Aktiv_montiert.SLDASM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]
2026-06-17 'final' arm
    [Aluprofil25x25.SLDPRT, Aluprofil40x20.SLDPRT, Arm_Baugr_20.05.26.SLDASM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]
2026-06-18 Spacer für Abdeckungen eingefügt
    [000_BG_Spannmechanismus_inkl. Montage.SLDASM, 00_BG_MT_Abstandshalter_Arm_vorne.SLDASM, 00_BG_MT_Abstandshalter_Deckel_Arm.SLDASM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]
2026-06-18 Arm korrekt benannt und platziert
    [00_BG_Arm.SLDASM, 17HE08-1004S.STEP, 17HE15-1504S.STEP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]
2026-06-18 Arm Getriebe und Nema hinzugefügt
    [ARM_Cricket_Drive_MK_II.step, ARM_Nema17_Mittel.STEP]
2026-06-18 Main Baugruppe ergänzt
    [000_BG_E-Passiv_montiert.SLDASM, 000_BG_Spannmechanismus_inkl. Montage.SLDASM, 00_BG_Flipper_Motor.SLDASM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]
2026-06-19 Abstandshalter für seitliche Abdeckungen eingefügt
    [00_BG_MT_Abstandshalter_Abdeckung_seitlich_ausschnitt.SLDASM, 00_BG_MT_Abstandshalter_Abdeckung_seitlich_komplett.SLDASM, 00_BG_Rahmen_mittelteil_inkl._Anbaute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]
2026-06-19 fixes for murder motors and quick start scripts
    [Lotti2.ros2_control.xacro, lotti2_controllers.yaml]
2026-06-20 minor fixes
    [Lotti2.ros2_control.xacro, lotti2_servo_config.yaml]
2026-06-20 cleanup and prep for tests
    [Aluprofil25x25.SLDPRT, Aluprofil40x20.SLDPRT, Arm_Baugr_20.05.26.SLDASM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]
2026-06-20 fixed flipper controller issue and adjusted drive_interface and diff drive controller
    [Lotti2.ros2_control.xacro, lotti2_controllers.yaml]
2026-06-21 more scripts added
    [Lotti2.ros2_control.xacro]
2026-06-21 multi camera launch fixed
2026-06-22 stand 22 14 uhr
    [Lotti2.ros2_control.xacro, lotti2_servo_config.yaml]
2026-06-22 flipper with PID controller untuned
    [Lotti2.ros2_control.xacro]
2026-06-24 pid again
    [Lotti2.ros2_control.xacro]
2026-06-25 pre flight check
    [Lotti2.ros2_control.xacro]
2026-06-26 added PCB Readme
2026-06-26 Added PCB Design files
    [1205Converter.kicad_sch, 2412Converter.kicad_sch, ARC_BOM_v1.xlsx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]
2026-06-26 renamed some files
    [1205Converter.kicad_sch, 2412Converter.kicad_sch, ARC_BOM_v1.xlsx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]
2026-06-26 new arm camera features implementation
2026-06-28 don't know exactly
    [Lotti2.ros2_control.xacro, Lotti_arm.xacro]
2026-06-29 start scripts and cameras
2026-06-30 flippers working (really this time)
    [Lotti2.ros2_control.xacro, lotti2_controllers.yaml]
2026-06-30 controller changes and qol
    [Lotti2.ros2_control.xacro, lotti2_controllers.yaml]
